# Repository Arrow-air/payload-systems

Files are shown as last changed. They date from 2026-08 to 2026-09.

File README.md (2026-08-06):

# Arrow Payload Systems

Open-source payload systems for Arrow UAV platforms.

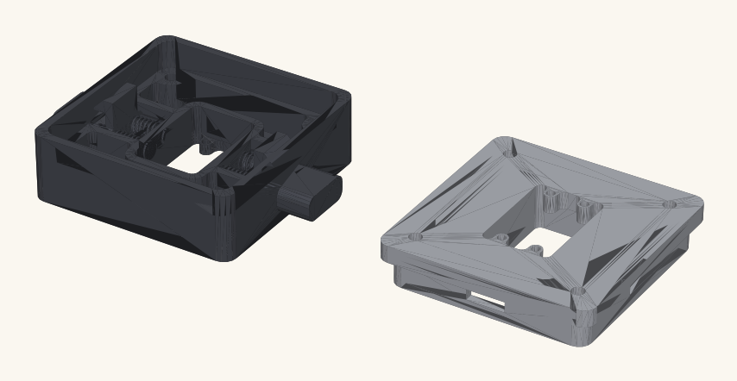
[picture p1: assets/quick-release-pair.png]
The Quiver quick-release pair: aircraft-side plate (left, with spring press-pins and release button) and the payload-side clip plate (right) that every payload bolts to


This repository is the home for community-designed payload attachments that interface with Arrow drones — starting with Quiver, and expanding to cover any Arrow platform that uses the standard attachment interface.

---

## What This Repo Is For

Arrow's drone platforms are designed from the ground up to be modular. The airframe is a carrier; the payload is the mission. This repo exists to:

- Document the **payload attachment interface standard** so anyone can design compatible payloads
- Host **design briefs, specifications, and build documentation** for community payload projects
- Coordinate development across contributors and track progress from concept to flight-ready

If you have an idea for a payload, or want to contribute to one already in progress, this is the place.

---

## The Attachment Interface

The authoritative specification is the **[Interface Control Document (ICD)](interface/ICD.md)** — per-port capabilities, pinouts, power rules, network conventions, and the mechanical mate. Payload designs declare the ICD version they target. Summary:

| Platform | Attachment Interface | Power | Data |
|---|---|---|---|
| **Quiver (PT3+)** | Quick-release, 3× hot-swap points (bottom + 2× side) | 12V_PL all ports (SSR-gated, ~25W guidance); 12VSW bottom only (2A) | Ethernet (all ports), CAN2/DroneCAN (all ports), 1× PWM aux per port |

Key facts (details and caveats in the ICD):

- **The three ports are not identical** — 12VSW and its relay exist only on the bottom port, PWM channel numbers differ per port, and the ports split across two Ethernet switch modules. Check the ICD §2 capability matrix.
- **Blind-mate electrical connection** via the Attachment Interface PCB (V1.4, validated): the aircraft carries spring-loaded pins, the payload side populates landing pads. Design files live in [project-quiver](https://github.com/Arrow-air/project-quiver/tree/main/task-grant-bounty/pt3/electronics/0003-Attachment-Interface-PCB).
- **No 5V, no UART** at the connector — payloads bring their own logic-rail DC-DC.
- **Mechanical mating geometry** (STEP) and mounting-point coordinates are vendored in [`interface/mechanical/`](interface/mechanical/).

---

## Payload Concepts

The following payload types have been identified by the Arrow community as high-value targets. They range from near-term buildable to longer-horizon R&D.

### 🟢 Active / In Progress

| Payload | Status | Thread |
|---|---|---|
| **Multispectral Camera** | Design brief complete, community discussion open | [#multi-spectral-camera](https://discord.com/channels/853833144037277726/1481622578132025364) |

### 🟡 Defined — Ready for Contributors

These payloads have detailed requirements written and are ready for someone to pick up.

| Payload | Description | Requirements Doc |
|---|---|---|
| **Universal Cargo Container** | Fixed or deployable cargo pod; stackable, manually transportable | [project-quiver](https://github.com/Arrow-air/project-quiver/blob/main/task-grant-bounty/equipment/attachment/0002-detailed_attachment_requirement_for_bounty/001-Universal_Cargo_Cont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) |
| **General Aerial LiDAR** | Nadir/forward LiDAR scanner; ≥32 channels, ≥20Hz, ≥1cm accuracy @ 100m | [project-quiver](https://github.com/Arrow-air/project-quiver/blob/main/task-grant-bounty/equipment/attachment/0002-detailed_attachment_requirement_for_bounty/002-General_Aerial_LiDAR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) |
| **Ground Target Machine Vision** | On-board ML inference for target ID/counting; KML/KMZ output | [project-quiver](https://github.com/Arrow-air/project-quiver/blob/main/task-grant-bounty/equipment/attachment/0002-detailed_attachment_requirement_for_bounty/003-Ground_Target_Machin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) |
| **Standard Magnification Camera** | 3-axis gimbaled; ≥1/2" sensor, 24mm + 85mm+ focal lengths | [project-quiver](https://github.com/Arrow-air/project-quiver/blob/main/task-grant-bounty/equipment/attachment/0002-detailed_attachment_requirement_for_bounty/004-Standard_Magnificati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) |
| **General Stabilized Sensor Carrier** | 3-axis gimbal; 1/4-20 mount; 5–8kg capacity; follow-focus optional | [project-quiver](https://github.com/Arrow-air/project-quiver/blob/main/task-grant-bounty/equipment/attachment/0002-detailed_attachment_requirement_for_bounty/005-General_Stabilized_S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) |
| **High Capacity Flood Light** | ~train-light brightness; 45–60° beam; 4000–4500K; flash/breathe modes | [project-quiver](https://github.com/Arrow-air/project-quiver/blob/main/task-grant-bounty/equipment/attachment/0002-detailed_attachment_requirement_for_bounty/006-High_Capacity_Flood_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) |

### 💡 Your idea here

The best payload is the one *you* actually need. Quiver is a multipurpose
platform — if there is an attachment you would use, build it. Sensors,
cargo, lighting, sampling, spraying, comms, safety systems: if it fits the
interface, it can fly. A longer inventory of community-discussed concepts
lives in the [possible attachments document](https://github.com/Arrow-air/project-quiver/blob/main/task-grant-bounty/equipment/attachment/0001-possible_attachment_list/information-note.md)
in project-quiver if you want inspiration.

Start a thread in the Arrow Discord, copy the
[payload template](payloads/_template/), and design against the
[ICD](interface/ICD.md). Payload development can be funded through Arrow
grants & bounties.

---

## How to Contribute

1. **Check the discussions** — see what's already being designed before starting fresh
2. **Open a discussion** — new payload idea? Start a thread and gather input before committing to design
3. **Start from the template** — when a payload is ready for design work, copy [`payloads/_template/`](payloads/_template/) to `payloads/<payload-name>/` and fill in its README (purpose, requirements, target port, ICD version)
4. **Design against the ICD** — any payload targeting Quiver must respect the [ICD](interface/ICD.md): port capabilities, pinout, power rules, and mechanical envelope. Run the ICD §8 checklist before requesting review.

### Repo Layout

```
interface/
├── ICD.md            ← the interface standard (versioned)
├── mechanical/       ← mating STEP files + mounting-point coordinates
└── pcb/              ← pointer to the Attachment Interface PCB in project-quiver
payloads/
├── _template/        ← copy me to start a new payload
└── <payload-name>/   ← one folder per payload: README, cad/, pcb/, software/, docs/
```

Payload folders are created when real design work starts — concepts live in the tables above until then.

---

## Community & Governance

- **Discord:** [#multi-spectral-camera](https://discord.com/channels/853833144037277726/1481622578132025364) and other payload channels in the Arrow server
- **Arrow DAO:** Payload development can be funded via Arrow grants & bounties
- **License:** [CERN-OHL-S v2](LICENSE) — same as project-quiver

---

*This repo is maintained by the Arrow community. All are welcome.*

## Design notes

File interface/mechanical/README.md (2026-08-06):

# Mechanical Interface — Quick-Release Mounting Points

Vendored from project-quiver (BOM 2100, `src/quiver/supporting_structure/attachment_interface/`).
These files are copies for payload-design convenience; the originals in
project-quiver are the source of truth.

## Files

| File | Part | Used |
|---|---|---|
| `2112_attach_plate.step` | Quick-release interface plate (aluminum) — the drone-side mechanism your payload clips into | 3× (all ports) |
| `2112_attach_plate_payload_side.step` | **Payload-side clip plate ("Replaceable Base")** — the part your payload bolts to. 50 × 50 mm footprint, 10.5 mm thick | 1× per payload |
| `2111_attach_spacer.step` | Side-port spacer (PETG) | 2× (left/right) |
| `2131_attach_spacer_bottom.step` | Bottom-port spacer with wiring notch (PETG) | 1× (bottom) |

The plate STEP contains the drone side of the quick-release mechanism
(fixed top, press pins, springs). Your payload provides the mating side.

## The payload-side plate (what your payload bolts to)

The quick-release is a **COTS aluminum clip-plate pair**
([Quick-Release Clip Plate, ~$34](https://www.alibaba.com/product-detail/Quick-Release-Clip-Plate-Clamp-Quick_1600982145247.html),
BOM item 2112 — order **without PCB**). Each set includes both halves:

- **Fixed half** (spring press-pins) — mounted on the aircraft.
- **Clip half** — this is the payload side. Bolt it to your payload's top
  surface, align it with the blind-mate PCB pads (orientation notch on the
  board silkscreen), and it clips into the aircraft's fixed half by hand.

Buy the same product and use the clip half; that guarantees mechanical
compatibility with the flying aircraft. The clip half is modeled in
`2112_attach_plate_payload_side.step` — design your payload's mounting
pattern against it, or start by bolting straight to the physical part.

## Mounting-point positions (drone coordinates)

Frame: origin at airframe center, **+Z up, +Y forward**. Positions are
interface-plate center-of-mass values from the PT3 master model (confirmed
accurate to the flying aircraft, 2026-08).

| Port | Plate position (x, y, z) mm | Mechanism faces |
|---|---|---|
| Bottom | (0, 0, −160.7) | −Z (down) |
| Side 1 / Right | (+185.65, −0.02, −71.0) | +X (outboard) |
| Side 2 / Left | (−185.65, +0.02, −71.0) | −X (outboard) |

The drone-side plate hardware is ~10 mm thick, so a bottom payload's top
mounting plane sits at roughly **Z = −171 mm**. Side ports include a 3 cm
extension adapter for clearance from the airframe body; cable ports face
sideways to prevent abrasion and water ingress.

## Designing the payload side

- Start from the parametric example in project-quiver:
  [`src/quiver/attachments/designs/example_plate/`](https://github.com/Arrow-air/project-quiver/tree/main/src/quiver/attachments/designs/example_plate)
  — it builds a placeholder plate positioned on the bottom interface and can
  render your design in place on the full drone CAD
  (`python -m quiver.attachments.designs.example_plate.assembly --show`).
- Envelope: no formal keep-out volumes are published yet. Practical limits:
  propeller disk clearance for anything wide, ground clearance on landing
  gear for bottom payloads, and the battery-slider travel for side payloads.
  When in doubt, load your STEP against the full drone assembly.

## TODO (tracked)

- [ ] Formal keep-out / envelope STEP exported from the full PT3 assembly
- [ ] Per-port structural mass limits

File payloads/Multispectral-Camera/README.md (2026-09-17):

# Quiver Multispectral Camera Mount V1 (MAPIR Survey3 RGN)

**Status:** flight-tested (prototype, see Remarks for unmet criteria)
**Target port(s):** bottom (as flown), side 1 (design intent)
**ICD version:** 1.0-draft
**Champion:** Erick Perdomo (errrks)
**Discussion:** https://dao.arrowair.com/t/bounty-v1-quiver-multispectral-camera-payload/156

# Status

`Valid, as built at Meetup 2026, flight tested 2026-08-13 (approximate). Information note for project-quiver T-11 (issue #257).`

Built by Erick Perdomo and Alperen with a camera supplied by Thomas. This README is the V1 information note. It records the hardware that flew, the flight controller configuration, the tests run and not run, and what V2 should change. The Meetup 2026 build pack is the design intent and is superseded here where they differ.

# Project Description

Fixed nadir mount for the MAPIR Survey3 RGN multispectral camera. The camera hangs in a printed saddle on four silicone damper balls under the JMRRC quick release clip plate. An LM2596 buck steps 12V_PL down for the camera's USB power input, and the flight controller drives the MAPIR HDMI PWM trigger cable directly over the port's PWM auxiliary channel. No microcontroller, no enclosure, no downlink. Images come off the microSD after flight.

Origin: DAO bounty 156, folded into an in-house meetup build charged to QGB-05. Bounty criteria (fit, stable 5 V power, trigger on each FC pulse, GPS tag, vibration isolation, IP5X dust protection) remain the evaluation baseline.

| | |
|---|---|
| Mass | Not weighed (design estimate ~300 g, built unit lighter) |
| Power | 12V_PL through an LM2596 buck at 5.3 V, ~2 W capturing |
| Data | PWM (FMU_CH1 as flown) |
| Port | bottom as flown, side 1 in design |

# Methodology

1. Parts: MAPIR Survey3 RGN (Thomas's unit), MAPIR HDMI PWM trigger cable, MAPIR USB Power+FPV cable, Zovfam LM2596 buck (Amazon B08BFKKDGD), silicone damper balls from workshop stock, Molex 204523-1201 housing with 79758-1149 leads, JMRRC male clip plate, Attach Interface PCB V1.4 payload side.
2. Printed body, damper plates, and camera saddle in PA6-CF. CAD in `CAD/MAPIR-Survey3N-RGN-adapter.step`.
3. Lens swapped from the wide lens to the narrow lens: unscrew the lens retaining ring, exchange the lens body, refocus by test shots on a distant target.
4. Buck trimmed to 5.3 V at its output, unloaded, before the camera was connected.
5. Flight controller output freed from the GPIO mask, PWM verified on the bench with Mission Planner DO_SET_SERVO at 1000 and 2000 µs.
6. Flight on the bottom port with RC channel 9 triggering. Internal battery removed.

# Results and Deliverables

## Camera

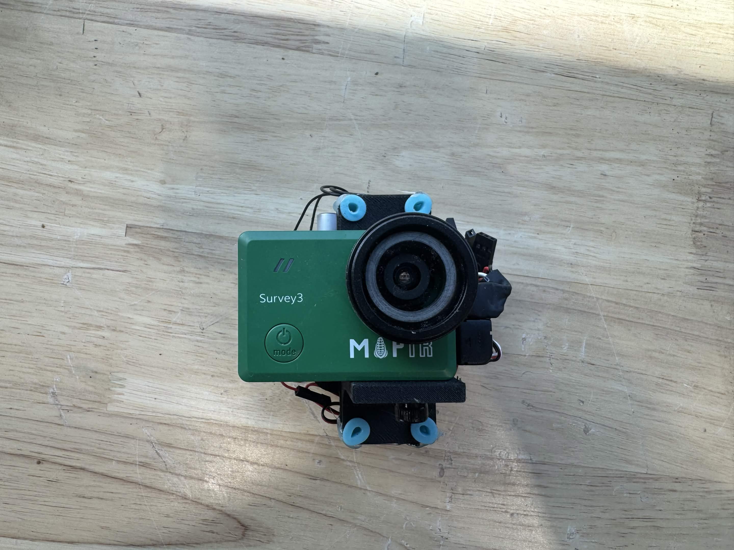
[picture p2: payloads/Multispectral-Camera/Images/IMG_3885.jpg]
Front: Survey3 RGN with the narrow lens, damper balls at the corners


- MAPIR Survey3, classic body, RGN filter, narrow lens (41° HFOV) after the swap.
- Capture mode single photo, RAW on (RAW plus JPG). MAPIR manual v3: RAW is only available in single capture mode.
- Internal battery out. The camera therefore reboots on every 12V_PL cycle.
- Firmware version, SD card model, and cable source not recorded.

## Mount

- JMRRC male clip plate with the Attach Interface PCB V1.4 payload side in its recess.
- PA6-CF body on the plate carries the buck on top and a damper plate below. A second damper plate on the camera saddle. Saddle clamps the camera body with one M3 socket head.
- Four blue silicone damper balls between the plates, hot glued. Source and durometer unknown (workshop stock).
- No enclosure, gasket, or SD door. No outboard arm (not needed on the bottom port). Single load path through the clip plate.
- Zip ties for lead strain relief.

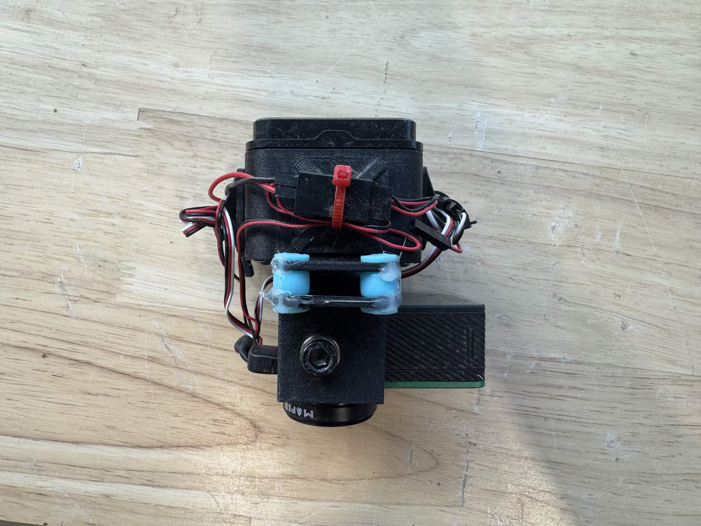
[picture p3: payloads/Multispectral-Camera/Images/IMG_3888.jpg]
Side: damper stack between the plates, saddle clamp bolt, zip tied leads


## Electrical

Power chain: 12V_PL (J1 pin 10) → LM2596 buck IN+ → 5.3 V OUT → MAPIR USB Power+FPV cable spliced to the buck output.

Buck listing specs (2026-09-17): input 3 to 40 V, output 1.3 to 35 V, 2 A continuous, 3 A peak with heatsink, 92% peak efficiency, 65 kHz, 30 mV ripple, thermal shutdown and current limit.

The MAPIR manual v3 states "wall chargers marked output 5V 1A." It does not mention 5.3 V. The 5.3 V setting was measured at the buck output unloaded and worked. The camera end under load was not measured. USB device limit is 5.25 V, so measure the camera end and trim down if needed.

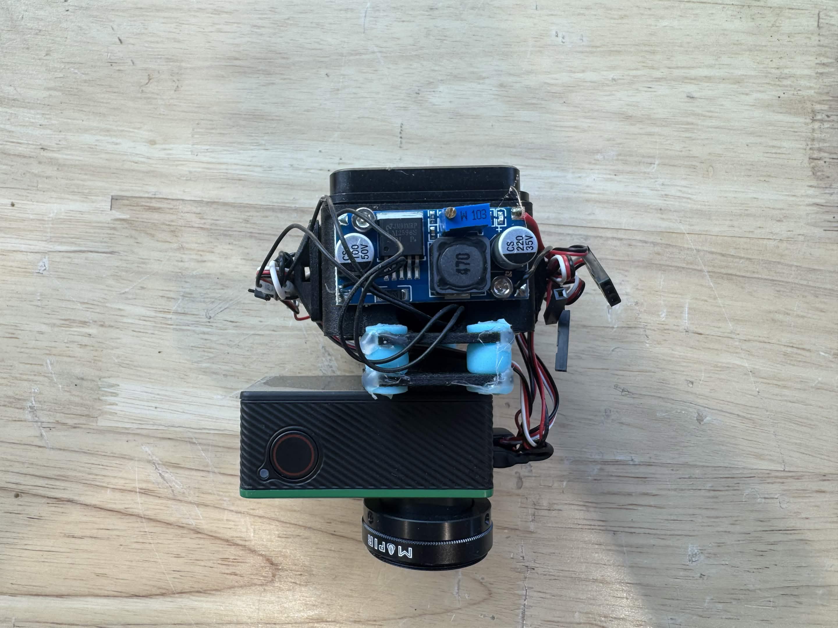
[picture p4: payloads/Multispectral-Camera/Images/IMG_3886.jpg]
Buck on the body top, damper stack, camera below


Harness on Attach Interface PCB J1:

| J1 pin | Signal | Connection |
|---|---|---|
| 8 | GND | Buck IN−, trigger cable ground |
| 10 | +12V (12V_PL) | Buck IN+ |
| 12 | FMU_CH1 | MAPIR trigger cable signal lead |

No inrush limiter, no fuse, no filtering.

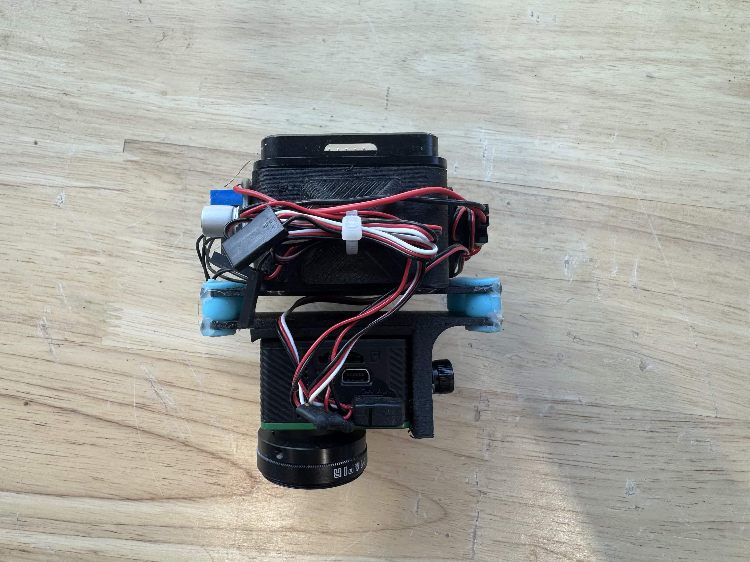
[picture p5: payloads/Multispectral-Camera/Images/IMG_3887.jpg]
Rear: clip plate pogo window, camera HDMI and USB ports with the trigger and power leads


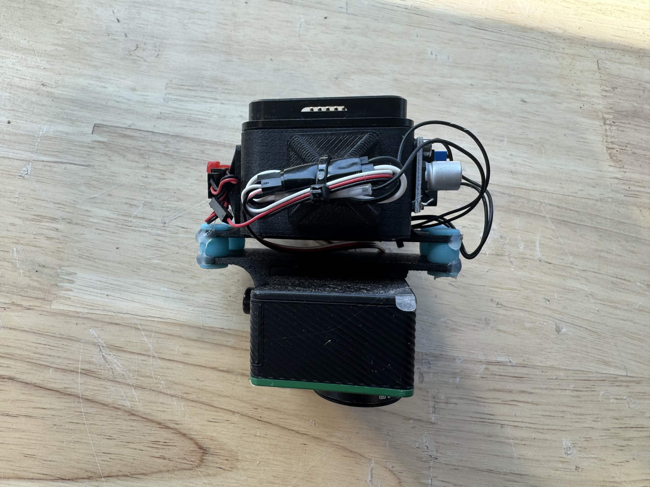
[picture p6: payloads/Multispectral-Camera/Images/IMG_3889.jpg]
Rear, harness dressed: clip plate slot at top, buck trimmer and capacitor at right, damper stack, camera body


## Trigger

FMU_CH1 servo PWM → J1 pin 12 → MAPIR HDMI PWM trigger cable → camera HDMI port. Trigger cable power lead unused.

MAPIR manual v3 PWM levels:

| Pulse | Camera action |
|---|---|
| 1000 µs | Neutral, camera does nothing |
| 2000 µs momentary | Capture |
| 1500 µs momentary | Enter media transfer mode, second pulse exits |

As flown the camera captured on every 2000 µs pulse from the 1000 µs idle.

**1500 µs hazard:** an output resting at trim, a three position switch center, or a slow slider puts the camera into media transfer mode and stops captures until another 1500 µs pulse. Use a two position switch and keep every failsafe path away from 1500.

## Flight controller configuration

Same channel mapping and GPIO mask procedure as the latch README (project-quiver config guide section 11.6). Camera values as flown (from recollection of a rewrite over the latch snapshot, verify on the vehicle):

```
SERVO_GPIO_MASK   12016     ; outputs 9, 15, 16 freed for PWM
SERVO9_FUNCTION   148       ; RCIN9Scaled, RC channel 9
SERVO9_MIN        1000      ; neutral
SERVO9_MAX        2000      ; capture
RELAY6_FUNCTION   1         ; 12V_PL rail (FMU_CH4, pin 53)
RELAY6_PIN        53
RELAY6_DEFAULT    0
```

Bench alternative: `SERVO16_FUNCTION = 0`, MIN/MAX 1000/2000, Servo 16 row High on the Mission Planner Servo/Relay page (side 2 port).

Not used: ArduPilot camera driver (CAM1 is already the SIYI at type 4). Mission triggering by distance is a V2 item and needs a second camera instance.

## Test record

| Test | Result |
|---|---|
| Bench trigger from Mission Planner, output 16 | Captured on every pulse, 2026-08-12 |
| Flight, bottom port, RC channel 9 | Captured on every trigger, RAW plus JPG |
| 12V_PL cycle via Relay 6 | Camera rebooted each cycle, recovered, accepted triggers |
| GPS geotag in EXIF (bounty GPS Tag) | Not checked. Camera top face points into the belly, no sky view |
| Camera end voltage under load (bounty Power) | Not measured |
| Mass (350 g budget) | Not weighed |
| IP5X (bounty Dust Protection) | Not built |

Photos in `Images/` (IMG_3885 to IMG_3889). Video: Arrow Discord and Twitter, meetup week of 2026-08-10.

## Deliverables

- `CAD/MAPIR-Survey3N-RGN-adapter.step`, `.stl` (CERN OHL-S v2)
- This README (CC BY 4.0)
- Flight controller configuration section 11.6 in project-quiver

# Remarks

1. **Geotag unverified and probably absent.** On the bottom port the built in GPS antenna faces the 2 mm aluminum lower plate. Pull the SD and check EXIF. V2 restores sky view on a side port or feeds NMEA from the vehicle.
2. **Power criterion open.** 5.3 V set unloaded at the buck, not locked, camera end not measured. The manual's stated requirement is 5 V 1 A.
3. **1500 µs media transfer mode.** Any output parked at trim stops captures. Guard in the RC setup and in any future camera driver integration.
4. **Battery out means a reboot on every rail cycle.** Camera boot time before it accepts triggers is unrecorded. Measure and add to the ground procedure. Battery in (the original decision) survives rail cycles but needs the charge current and thermal check.
5. **Capture interval.** RAW plus JPG limits capture to roughly one per 2.5 to 3 s. Faster mission triggering drops frames silently.
6. **No enclosure, no inrush, no fuse.** IP5X criterion not attempted.
7. **Dampers.** Unknown durometer, hot glued. Vibration isolation criterion asks for a documented spec.
8. **Bottom port sharing with the latch.** SERVO9 endpoints differ (1000/2000 vs 1315/1750) and both use RC channel 9. Rewrite at every swap.
9. **Lens swap.** Filter position during the swap not recorded. Confirm with Thomas whether the RGN filter is lens mounted or sensor mounted on this unit.
10. **Print material.** All printed parts are PA6-CF (confirmed 2026-09-17), not the PETG-CF called out in the meetup build conventions. Dry the filament before printing. Heat set insert bores may creep if parts are stored humid. Filament brand and drying procedure not recorded.

# V2 Recommendations

- Side port mount with a plain PETG GPS window per the build pack, or vehicle NMEA to the camera.
- Gasketed enclosure with SD door for IP5X.
- Second ArduPilot camera instance (servo type) for mission triggering, with 1500 µs excluded from every path.
- Buck enclosure, trimmer lock, inrush NTC, local fuse.
- Measured mass, camera end voltage under load, boot time after rail power.
- Decide battery in or out. Record the damper spec.

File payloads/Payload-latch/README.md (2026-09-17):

# Quiver Actuated Payload Latch V1

**Status:** flight-tested (prototype, see Remarks for unmet criteria)
**Target port(s):** bottom
**ICD version:** 1.0-draft
**Champion:** Erick Perdomo (errrks)
**Discussion:** https://dao.arrowair.com/t/bounty-v1-quiver-actuated-payload-latch/155

# Status

`Valid, as built at Meetup 2026, flight tested 2026-08-13 (approximate). Information note for project-quiver T-11 (issue #257).`

Built by Erick Perdomo and Alperen. This README is the V1 information note. It records the hardware that flew, the flight controller configuration that drove it, the tests that were and were not run, and what V2 should change. The design intent lives in the Meetup 2026 build pack and is superseded here where they differ.

# Project Description

Servo actuated cargo hook for slung loads on the Quiver bottom port. An off the shelf aluminum sliding pin release block, driven by a standard size servo, is carried on a printed PA6-CF bracket bolted to the JMRRC quick release clip plate. The flight controller drives the servo directly over the port's PWM auxiliary channel. There is no microcontroller and no return spring in V1.

Origin: DAO bounty 155 ($500 USDC, unclaimed), folded into an in-house meetup build charged to QGB-05. The bounty requirements (2 kg safe working load, under 250 g, 3.3 V GPIO trigger, mechanically closed on power loss, 20 cycle reliability) remain the evaluation baseline. See Remarks for which are met.

| | |
|---|---|
| Mass | Not weighed (design estimate ~240 g) |
| Power | 12V_PL through an LM2596 buck at 6 V. Idle under 1 W, servo stall bound ~15 W for under 1 s |
| Data | PWM (FMU_CH1) |
| Port | bottom |

# Methodology

1. Parts per the meetup build pack BOM: powerday 995 alloy release unit (Amazon B07HKF6C5P), Deegoo-FPV MG995 servo (Amazon B07NQJ1VZ2), Zovfam LM2596 buck 10 pack (Amazon B08BFKKDGD), Molex 204523-1201 housing with 79758-1149 pre-crimped leads, JMRRC male clip plate, Attach Interface PCB V1.4 payload side.
2. Bracket modeled and printed in PA6-CF, heat set M3 inserts for the servo frame. CAD in `CAD/V1-Servo-Payload-Mount.step`.
3. Servo endpoints measured at linkage fitting with the servo on a bench PWM source: 1315 µs pin home, 1750 µs pin retracted.
4. Buck trimmed to 6 V at its output with a DMM, unloaded, before the servo was connected.
5. Flight controller outputs freed from the GPIO mask and configured for RC passthrough (see Results, FC configuration).
6. Bench cycles from Mission Planner on outputs 9, 15, and 16, then two flights with a 370 g load and one 1 kg drop.

# Results and Deliverables

## Mechanism

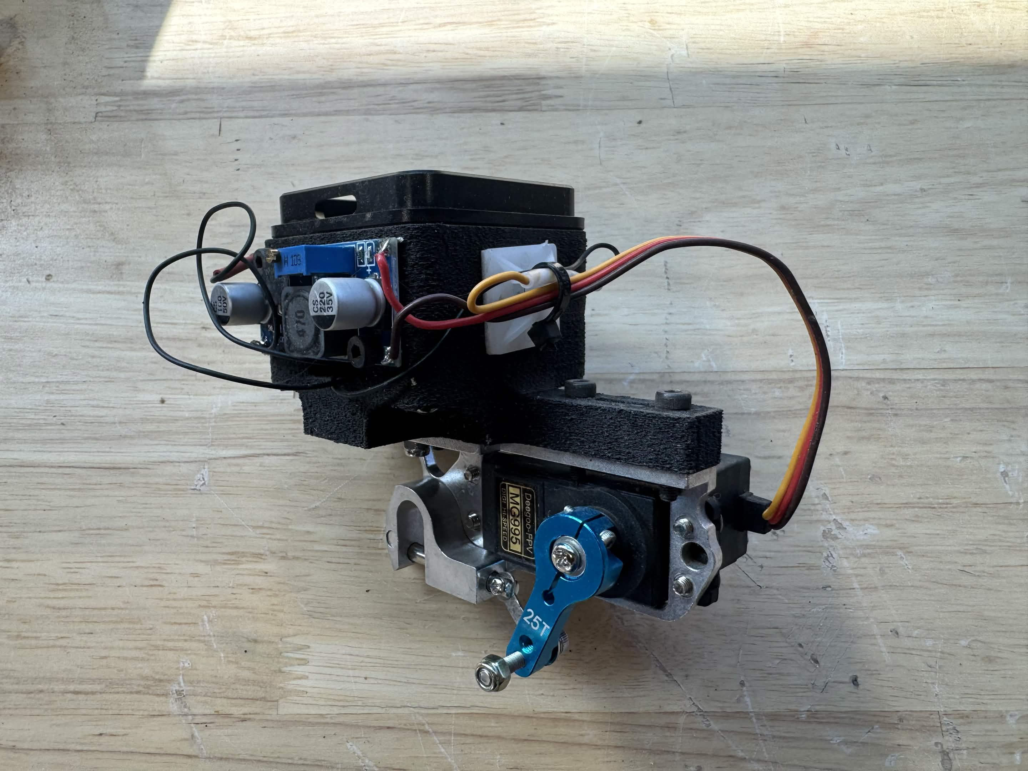
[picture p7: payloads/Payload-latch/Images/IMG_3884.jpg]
Assembly overview: buck on the bracket top, powerday block and MG995 below


- powerday 995 aluminum pin block with its servo frame. MG995 with a blue 25T aluminum horn. M3 bolt and nyloc nut as the linkage pivot.
- **No return spring.** The servo drives and holds the pin in both positions. With power removed the pin is retained by gear friction only.
- One L shaped PA6-CF bracket. Four M3 socket heads into heat set inserts hold the servo frame. The buck sits exposed on the bracket top face. The bracket bolts to the JMRRC male clip plate, which carries the Attach Interface PCB V1.4 payload side (10 pads) on 4× M2.
- Printed zip tie saddle on the bracket side for lead strain relief.
- Single structural path through the clip plate. No secondary strap.

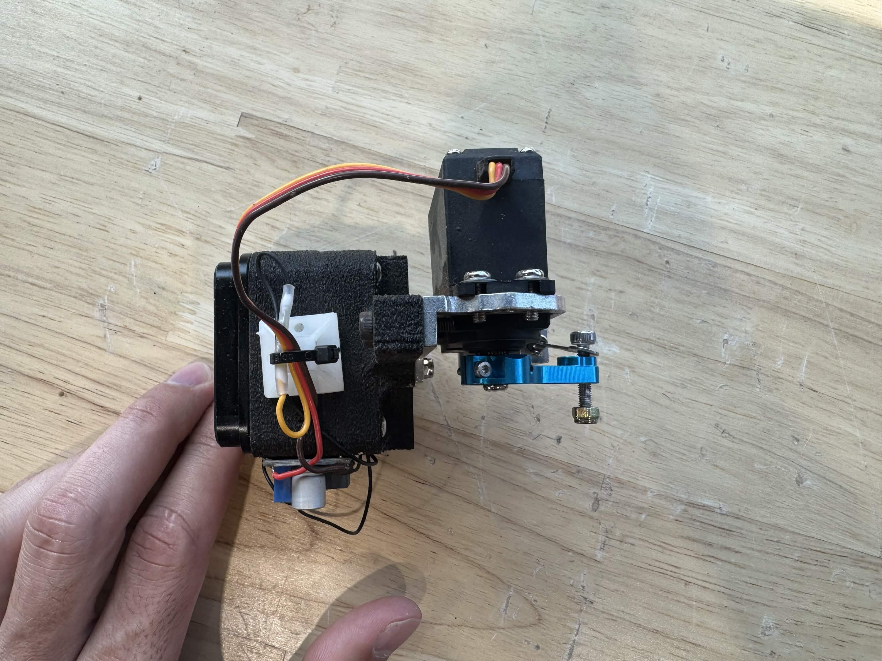
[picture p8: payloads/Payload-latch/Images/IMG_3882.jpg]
Side view: servo on the aluminum frame, 25T horn, linkage to the pin carrier, zip tie saddle


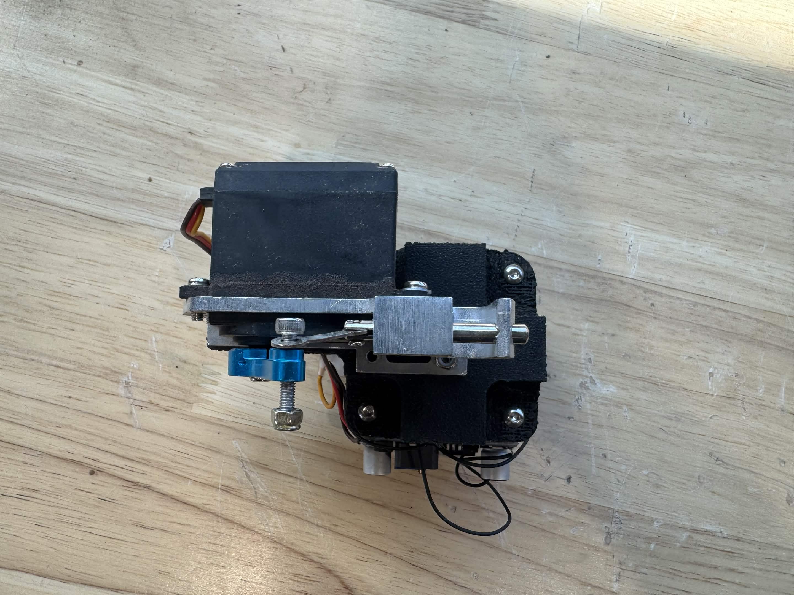
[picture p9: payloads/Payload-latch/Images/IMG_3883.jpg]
Underside: pin extended through the block, linkage pivot bolt


## Electrical

Power chain: 12V_PL (J1 pin 10) → LM2596 buck IN+ → 6 V OUT → servo. Servo power leads soldered to the buck output pads.

Buck listing specs (2026-09-17): input 3 to 40 V, output 1.3 to 35 V, 2 A continuous, 3 A peak with heatsink recommended above 2 A or 15 W, 92% peak efficiency, 65 kHz, thermal shutdown and current limit, 43 × 21 × 14 mm.

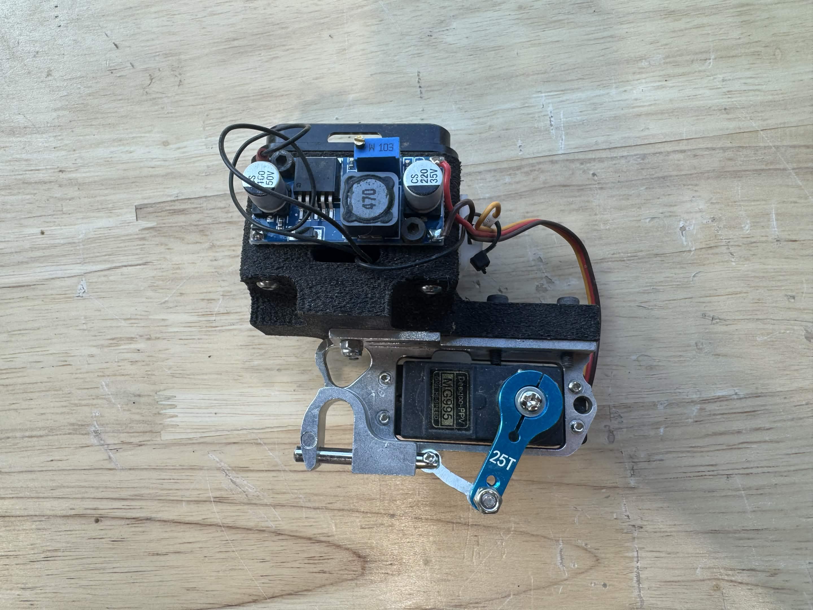
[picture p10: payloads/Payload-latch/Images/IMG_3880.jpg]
Top view: LM2596 buck with trimmer and capacitors exposed, Molex housing to the right


Harness on Attach Interface PCB J1:

| J1 pin | Signal | Connection |
|---|---|---|
| 8 | GND | Buck IN−, servo ground via buck OUT− |
| 10 | +12V (12V_PL) | Buck IN+ |
| 12 | FMU_CH1 | Servo signal lead, solder heat shrink joint |

No inrush limiter, no fuse, no series resistor, no pulldown, no bulk capacitor beyond the buck's own output cap.

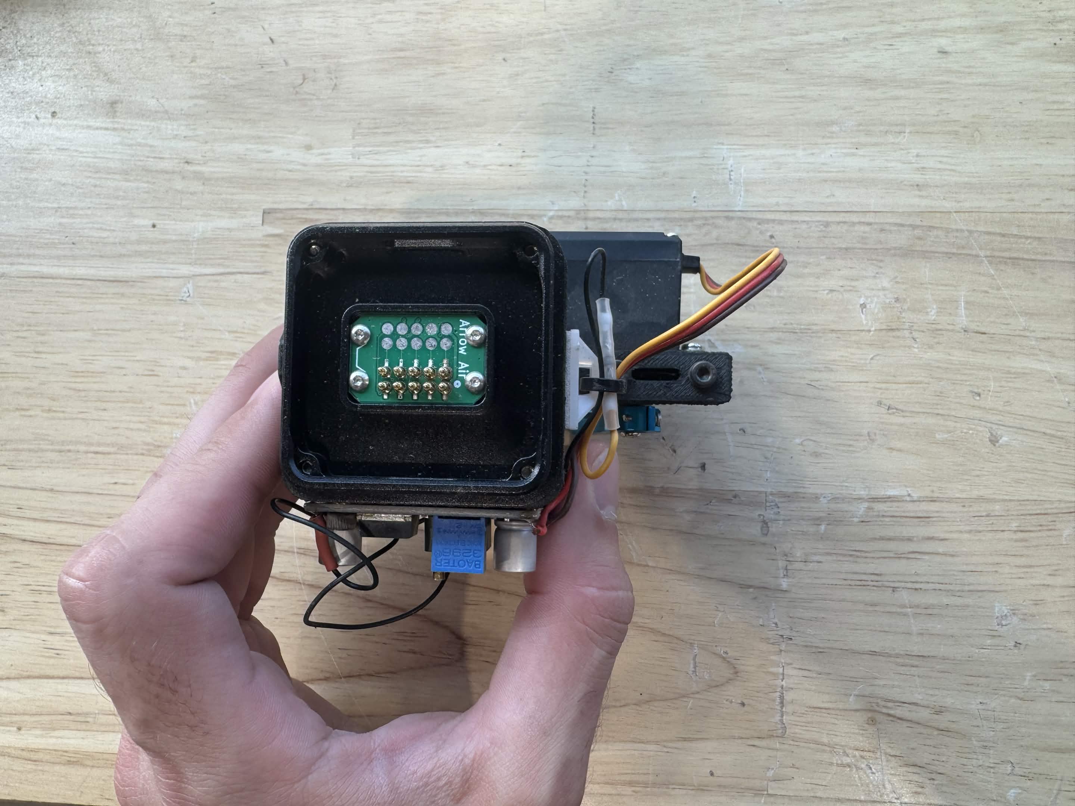
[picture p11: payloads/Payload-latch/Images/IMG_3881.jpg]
Clip plate face: Attach Interface PCB V1.4 payload side in the recess, zip tie saddle and signal joint at right


## Flight controller configuration

Confirmed on the second Dev-Kit, 2026-08-12. Full procedure in project-quiver `docs/Operations/Initial-Configuration-Guide.md` section 11.6.

| Port | FC pin | ArduPilot output |
|---|---|---|
| Bottom | FMU_CH1 | SERVO9 |
| Side 1 | FMU_CH7 | SERVO15 |
| Side 2 | FMU_CH8 | SERVO16 |

The HOU baseline ships `SERVO_GPIO_MASK = 65520`, claiming outputs 5 through 16 as GPIO. A masked output produces no PWM. Clear the bit for the port in use (bottom only: 65264, all three payload channels: 16112), write, reboot. The flown unit used 12016.

Latch parameters as flown (from a work in progress snapshot, verify on the vehicle):

```
SERVO_GPIO_MASK   12016     ; outputs 9, 13, 15, 16 freed for PWM
SERVO9_FUNCTION   148       ; RCIN9Scaled, RC channel 9 scaled into MIN/MAX
SERVO9_MIN        1315      ; locked
SERVO9_MAX        1750      ; released
RELAY6_FUNCTION   1         ; 12V_PL rail (FMU_CH4, pin 53)
RELAY6_PIN        53
RELAY6_DEFAULT    0
```

Bench alternative: `SERVO9_FUNCTION = 0` and drive the Servo 9 row on the Mission Planner Flight Data → Servo/Relay page with Low/High typed as 1315/1750.

Transmitter: any radio with channel 9 on a two position switch. Low is locked. The switch is the operator's choice.

Ground procedure: Relay 6 on, confirm the pin is home, load the ring or loop onto the pin, arm. Any Relay 6 toggle in flight power cycles the latch.

## Test record

| Test | Result |
|---|---|
| Bench, no load, repeated cycles from outputs 9, 15, 16 | Passed |
| Two flights, 370 g bottle on a zip tie loop, drops at 10 m and 5 m, RC channel 9 | Released cleanly both times, mechanism unaffected |
| 1 kg first aid kit drop | Released cleanly |
| 2 kg static load, 20 cycles (bounty reliability) | Not run |
| Power loss with load hanging (bounty failsafe) | Not run |
| RC failsafe behavior | Not run |
| Mass, current, buck under load | Not measured |

Photos in `Images/` (IMG_3880 to IMG_3884). Drop videos: Arrow Discord and the Arrow Twitter account, meetup week of 2026-08-10.

## Deliverables

- `CAD/V1-Servo-Payload-Mount.step`, `.stl` (CERN OHL-S v2)
- This README (CC BY 4.0)
- Flight controller configuration section 11.6 in project-quiver

# Remarks

1. **Failsafe criterion not met.** No spring. An unpowered servo holds the pin by friction only, and 12V_PL drops on every Relay 6 cycle and reboot. Untested with load. V2 needs a mechanical lock on power loss.
2. **Reliability criterion not run.** 20 cycles at 2 kg still owed. Flown loads were 370 g and 1 kg.
3. **Structure.** Single load path through the clip plate. The ICD and the requirement docs ask for two rigid connections or a rated tether.
4. **Electrical protection.** No inrush limiting (AB-1), no local fuse, exposed buck and trimmer, trim set unloaded and not locked. A stalled MG995 (~2.5 A at 6 V) exceeds the buck's 2 A continuous rating and relies on the module's thermal shutdown.
5. **Signal loss.** No pulldown. Servo behavior with a floating signal is the retention path when the FC output stops. Characterize it.
6. **Bottom port sharing.** The V1 multispectral camera also flies on the bottom port with SERVO9 at 1000/2000. Swapping payloads means rewriting SERVO9_MIN/MAX. A stale 1000 µs low endpoint drives the latch servo past its lock stop.
7. **Parameter snapshot.** The saved WT file is work in progress and also carries `SERVO13_FUNCTION = 148`, presumed a leftover. Verify against the live vehicle.
8. **Print material.** All printed parts are PA6-CF (confirmed 2026-09-17), not the PETG-CF called out in the meetup build conventions. Dry the filament before printing. Heat set insert bores may creep if parts are stored humid. Filament brand and drying procedure not recorded.

# V2 Recommendations

- Mechanical lock on power loss: return spring or over center pin geometry.
- Enclosed electronics: buck in a printed pocket, trimmer locked, leads captive.
- Inrush NTC and local fuse on the 12 V input.
- Second structural path.
- Larger packages with a different loading and unloading mechanism (Erick).
- Measured mass, servo hold and stall current at 6 V, buck temperature.
- Keep FC only PWM or reintroduce an MCU for debounce, stall guard, and signal loss lock. Decide from the signal loss test.
- Per payload parameter file for bottom port hot swaps, or dedicate ports.

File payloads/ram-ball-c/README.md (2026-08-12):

# RAM Ball C

**Status:** prototype (first article printed in PA6-CF)
**Target port(s):** bottom / side 1 / side 2 (mechanical-only payloads work on any port)
**ICD version:** 1.0

One 3D-printed part that bolts to the payload-side quick-release clip plate
and exposes a **1.5" RAM Size-C ball**, so anything in the RAM ecosystem
(double-socket arms, cradles, cameras, antennas…) can hang off a Quiver
mounting point and be re-aimed without tools. Wiring from the attachment interface PCB
still comes through.

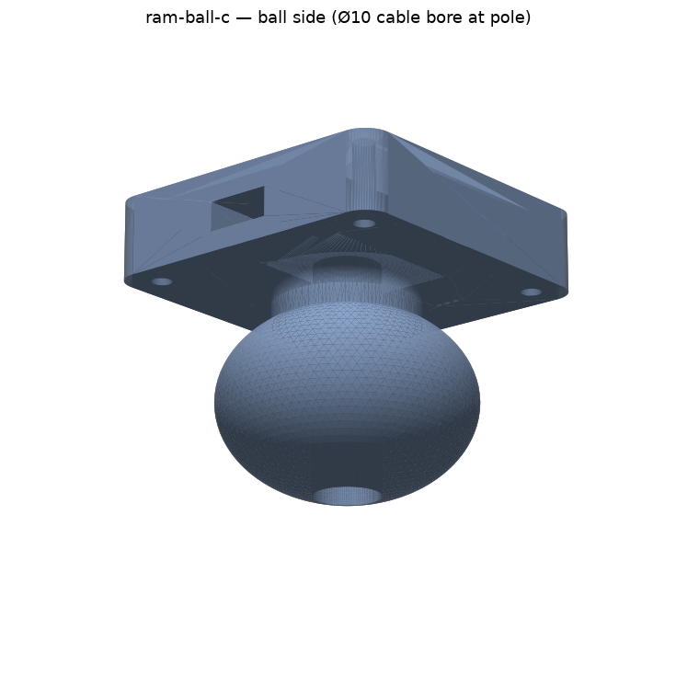
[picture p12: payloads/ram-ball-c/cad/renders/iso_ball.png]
ball side


## What it does

Clips onto any Quiver port via the standard quick-release, presents a Size-C
ball pointing away from the aircraft (down on the bottom port, outboard on the
sides). Two wiring routes from the attachment interface PCB:

- **Side channel** — 10 × 6 mm slot from the PCB well out the −Y face.
- **Axial bore** — Ø10 mm straight down the neck and out the ball's bottom
  pole, for wiring that should arrive at the mounted device. The bore exits
  inside the pole cap (~15° half-angle), well clear of the band a RAM socket
  clamps (verified: surface solid ±45° around the equator).

## Requirements

| | |
|---|---|
| Mass | ~75 g printed solid + clip half + fasteners ≈ 150 g, before the RAM arm and device |
| Power | none itself; pass-through wiring only |
| Data | pass-through wiring only |
| Port | any |

Load guidance: RAM rates C-size arms to roughly 1–2 kg in vibration
environments. Keep the hung mass + arm well inside the platform's payload
budget and treat >1 kg on a printed ball as needing a pull test first (same logic as the
capsule dispenser's RT-13 retention test).

## Geometry provenance

Interface dims are **measured, not assumed** — they come from the
capsule-dispenser r6 containment scan of
[`2112_attach_plate_payload_side.step`](../../interface/mechanical/)
(see `capsule-dispenser/cad/dispenser.py`, "clip-plate map"; r5 of that
project bolted into the blind-mate window by trusting eyeballed numbers):

- mount pattern 4× Ø3 at (±19, ±19)
- blind-mate shaft 16 × 24 through the plate; the payload-side pads PCB
  mounts to the plate's own tabs and hangs below it
- clip plate 50 × 50 × 10.5 mm

The part's well (16.6 × 24.6 × 12 deep, sharp corners) swallows the PCB, its
Molex J1 and a service loop. The square mount pattern *could* be assembled
90° off — but then the plate's 16 × 24 shaft crosses the well and the PCB
lands on the well rim, so wrong assembly is physically blocked. Engraved
triangle on the +Y wall (apex toward the plate) marks aircraft-forward on
the bottom port.

## Build

- **Print:** PA6-CF is what the first article was printed in and is ideal
  (stiff, strong, wear-resistant ball surface); PETG/ASA also work. 100 %
  infill (it's small; the ball and neck carry the load), 0.12–0.16 mm
  layers, ball-side up with the top face on the bed.
  The well roof and slot bridge ≤ 16 mm — no supports needed; supports OFF
  under the ball (the tangent neck keeps overhangs gradual).
- **Hardware:** 4× Ø3.2 mounting holes straight through the 16 mm body,
  matching the clip half's (±19, ±19) pattern (BOM 2112, see
  [`interface/mechanical/`](../../interface/mechanical/README.md)).
- A rigid printed ball grips fine in RAM arms but damps less than RAM's
  rubberized balls; if a device turns out vibration-sensitive, the fix is at
  the device end (RAM shock plate) or a marine-grade steel C ball on a
  50 × 50 AMPS adapter plate instead of this part.

## Folder layout

- `cad/ram_ball_c.py` — parametric source (build123d). Running it exports
  `ram_ball_c_adapter.stl` / `.step` next to itself.
- `cad/verify_ram_ball_c.py` — independent checks on the exports (trimesh
  containment + STEP face queries): envelope, mount-hole pattern, well clear of
  the full board footprint, both cable paths, ball diameter, clamp-band
  integrity. All 12 pass on the committed exports.
- `cad/renders/` — preview renders.

## Compliance

ICD §8: mechanical-only payload; no power drawn, no CAN termination, no
network presence. Envelope: 48 × 48 mm footprint inside the 50 × 50 clip
plate, 58.6 mm tall below the mating plane — on the bottom port the ball
bottom sits at Z ≈ −230, far above landing-gear ground contact (≈ −548).
Nothing protrudes above the mating plane.

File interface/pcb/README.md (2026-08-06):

# Attachment Interface PCB — pointer

The blind-mate PCB design lives in project-quiver and is **not duplicated
here**:

- Current revision: **V1.4** —
  [`0003-Attachment-Interface-PCB/2026-Update/`](https://github.com/Arrow-air/project-quiver/tree/main/task-grant-bounty/pt3/electronics/0003-Attachment-Interface-PCB/2026-Update)
  (spring-loaded pin blind-mate, validated)
- Original v1.2 documentation and pinout:
  [`0003-Attachment-Interface-PCB/README.md`](https://github.com/Arrow-air/project-quiver/blob/main/task-grant-bounty/pt3/electronics/0003-Attachment-Interface-PCB/README.md)

**For payload designers:** you populate the **pads-only side** (U11–U20
landing pads); the aircraft carries the spring pins. Order the same board,
populate per your side, mount with 4× M2. Electrical details and the
CAN1→CAN2 labelling caveat are in the [ICD](../ICD.md) §5.

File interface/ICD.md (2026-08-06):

# Quiver Payload Attachment Interface — Interface Control Document (ICD)

**ICD version:** 1.0-draft
**Applies to:** Quiver PT3 and later
**Source of truth:** the aircraft-side hardware is owned by
[project-quiver](https://github.com/Arrow-air/project-quiver). This document is
derived from the canonical KiCad sources (`src/pcb/main_pcb/`) and CAD
(`src/quiver/supporting_structure/attachment_interface/`) and is versioned so
payload designs can declare what they were built against. If this document and
the project-quiver sources disagree, the sources win — and please file an issue.

---

## 1. Overview

Quiver carries payloads on **three hot-swappable quick-release mounting
points**: one on the belly (bottom) and one on each side of the battery
compartment. Each point provides the same mechanical mate and a blind-mate
electrical connection carrying power, Ethernet, CAN, and one PWM auxiliary
channel. Payloads require no tools to install or remove.

Platform budget: **25 kg MTOW, 5–8 kg total payload capacity** across all
mounting points. Per-port structural limits are not yet formally specified;
see §6.

## 2. Port capability matrix

The three ports are **not identical**. Design against the port you target:

| Capability | Bottom (J31) | Side 1 / Right (J29) | Side 2 / Left (J30) |
|---|---|---|---|
| **12V_PL** — main 12 V payload rail | ✓ | ✓ | ✓ |
| **12VSW** — relay-switched 12 V (2 A fused) | ✓ | — | — |
| **CAN2** (DroneCAN) | ✓ | ✓ | ✓ |
| **Ethernet** 100BASE-T | ✓ (switch 1) | ✓ (switch 1) | ✓ (switch 2) |
| **PWM aux channel** | FMU_CH1 | FMU_CH7 | FMU_CH8 |
| Suggested static IP | 192.168.144.100 | 192.168.144.101 | 192.168.144.102 |

## 3. Power

### 12V_PL (all ports)
- Sourced from the Main PCB 12 V rail through two series fuses and a
  **solid-state relay (U5)** controlled by flight-controller channel
  **FMU_CH4**. Enabled by default in the standard configuration, so it behaves
  as always-on — but it is *not* hardwired. The FC can drop and restore the
  rail (e.g. to hard power-cycle a hung payload). **Payloads must tolerate
  power appearing late, being removed at any time, and repeated cycling.**
- The rail is shared by all three ports: one SSR, common fusing. Budget
  guidance: design within **~25 W per port** and verify total draw against
  Main PCB limits before exceeding.

### 12VSW (bottom port only)
- 12 V switched through mechanical relay **K1** (SPST-NO, controlled by
  **FMU_CH2**), fused at **2 A** (F1). Intended for FC-commanded on/off loads
  (originally the brush-bullet dispenser motor). Max ~24 W.

### Other voltages
- **No 5 V or 3.3 V is provided.** Payloads needing logic rails bring their own
  DC-DC (e.g. Mean Well SD-25B-05 class buck for 5 V).
- **No UART** is available at the payload connector.

## 4. Data

### Ethernet
- 100BASE-T, one TX and one RX differential pair per port, via two Ethernet
  switch modules on the Main PCB (bottom and side 1 on switch 1, side 2 on
  switch 2).
- The Quiver network is a **flat static 192.168.144.0/24 — no DHCP** (Siyi
  firmware conflicts with DHCP servers). Payloads use static IPs from the
  developer range **.100–.199**; recommended per-port assignments in §2.
- Reserved addresses (do not use): .11, .12, .20, .25, .50 (companion Pi),
  .51 (flight controller), .60. See the
  [Quiver SDK Developer Guide](https://github.com/Arrow-air/project-quiver/blob/main/docs/Develop-Attachments-Software/Quiver-SDK-Developer-Guide.md)
  for the full map and the companion-computer service architecture.

### CAN
- **CAN2 bus, DroneCAN protocol**, shared by all three ports plus the
  companion computer. A 120 Ω termination (R14) is switchable on the Main PCB
  (S2). **Payloads must not add bus termination** without coordinating with
  the airframe configuration.

### PWM auxiliary
- One direct flight-controller PWM output per port (see §2 for channel
  mapping). Note the channel differs per port — firmware/Lua that assumes
  FMU_CH1 only works on the bottom port.

## 5. Connector chain and pinouts

Main PCB (J31/J29/J30 power+CAN+PWM, 6-pos 2.50 mm; J39/J37/J38 Ethernet,
4-pos) → harness → **12-pin Molex locking connector** on the Attachment
Interface PCB → **spring-pin blind-mate** across the quick-release → payload.

### Attachment Interface PCB (the blind-mate)
- Design files: [project-quiver `0003-Attachment-Interface-PCB`](https://github.com/Arrow-air/project-quiver/tree/main/task-grant-bounty/pt3/electronics/0003-Attachment-Interface-PCB),
  current revision **V1.4** (`2026-Update/`).
- One board layout serves both sides: the **drone side populates spring-loaded
  pins (U1–U10)**; the **payload side populates only the enlarged landing pads
  (U11–U20)**. Alignment is provided by the quick-release mechanism; a
  silkscreen notch marks orientation.
- The spring-pin mate configuration is **validated** (electrically tested).
- Board: 23.5 × 15.8 mm, 1.2 mm FR4, 4× M2 mounting holes.

**10-pin blind-mate pinout** (drone-side pins → payload-side pads):

| Pin | Function |
|---|---|
| 1 | ETH_RX+ |
| 2 | 12VSW *(bottom port only; unconnected on sides)* |
| 3 | ETH_RX− |
| 4 | GND |
| 5 | ETH_TX+ |
| 6 | +12V (12V_PL) |
| 7 | ETH_TX− |
| 8 | FMU_CHx (per-port channel, §2) |
| 9 | CAN2_H *(labelled CAN1_P on board)* |
| 10 | CAN2_L *(labelled CAN1_N on board)* |

**12-pin Molex J1** (harness side, Molex 2077601281 / mate 2045231201):
doubled power and ground pins for current capacity — pinout in the
[Attachment Interface PCB README](https://github.com/Arrow-air/project-quiver/blob/main/task-grant-bounty/pt3/electronics/0003-Attachment-Interface-PCB/README.md).

## 6. Mechanical

See [`mechanical/`](mechanical/) for the vendored STEP files, mounting-point
positions in drone coordinates, and envelope guidance. Summary:

- The quick-release mechanism is a **COTS aluminum clip-plate pair** (BOM
  2112): the aircraft carries the fixed half (spring press-pins) at each
  port; **your payload carries the mating clip half of the same product** —
  see `mechanical/` for ordering info. PETG spacers mount the aircraft-side
  plates to the airframe. Side ports sit on 3 cm extension adapters for body
  clearance; the bottom spacer has a wiring notch.
- Drone coordinate frame: **origin at airframe center, +Z up, +Y forward.**
  Bottom interface plate at Z ≈ −160.7 (payload mounting plane ≈ −171);
  side plates at X ≈ ±185.7.
- Per-port structural mass limits: **not yet formally specified** — the
  platform-level 5–8 kg budget governs. Heavy payloads (>3 kg on a single
  port) should be reviewed against the airframe before flight.

## 7. Software integration

Payloads integrate through the companion computer (Raspberry Pi, .50):
DroneCAN devices are bridged to telemetry; Ethernet payloads get REST/WebSocket
pipelines to Quiver Hub (telemetry, point cloud, camera/WebRTC, custom payload
apps). Start with the
[Quiver SDK Developer Guide](https://github.com/Arrow-air/project-quiver/blob/main/docs/Develop-Attachments-Software/Quiver-SDK-Developer-Guide.md).

## 8. Designing a payload — checklist

1. Pick your port(s) from the capability matrix (§2).
2. Mechanical: mate to the quick-release plate; stay inside the envelope
   (§6 / `mechanical/`); mind prop clearance for wide payloads.
3. Electrical: payload-side Attachment Interface PCB (pads-only population),
   own DC-DC for logic rails, tolerate 12V_PL power cycling, no CAN
   termination.
4. Network: static IP in the assigned range, or DroneCAN on CAN2.
5. Software: integrate via the SDK guide's payload pipelines.
6. Declare the ICD version your design targets in your payload README.

## Revision history

| ICD version | Date | Changes |
|---|---|---|
| 1.0-draft | 2026-08-06 | Initial ICD from verified PT3 Main PCB (current KiCad netlist), Attachment Interface PCB V1.4, and BOM 2100 CAD. |

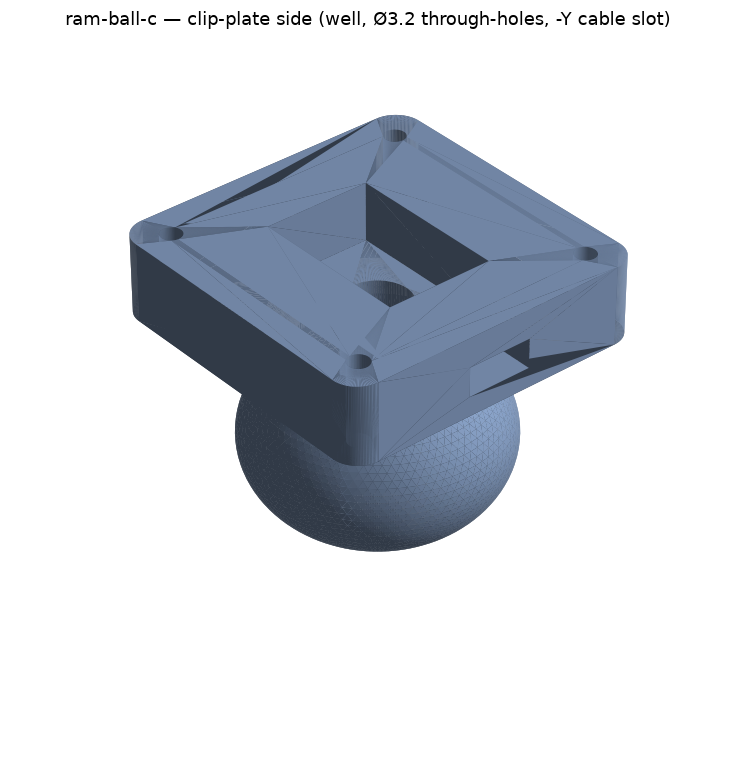
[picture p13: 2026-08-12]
payloads/ram-ball-c/cad/renders/iso_top.png

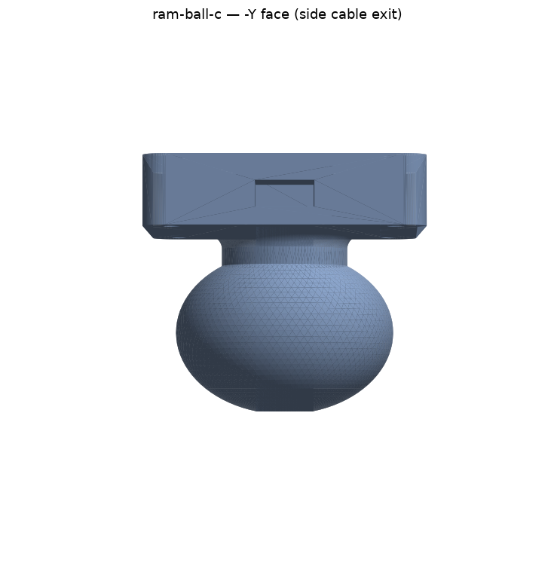
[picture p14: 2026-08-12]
payloads/ram-ball-c/cad/renders/front.png

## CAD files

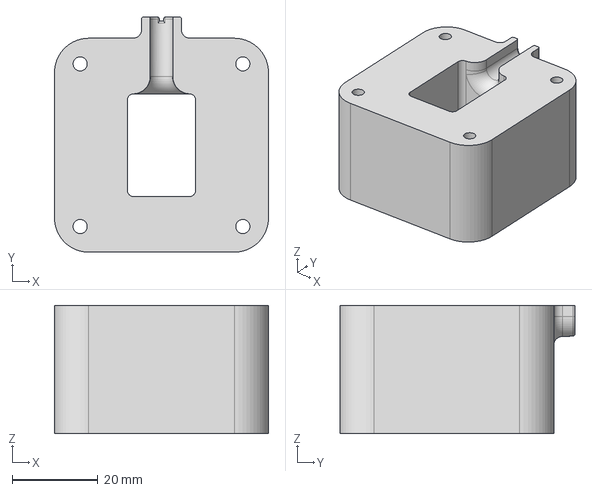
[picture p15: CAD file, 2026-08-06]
interface/mechanical/2131_attach_spacer_bottom.step
50.0 x 55.0 x 30.0 mm

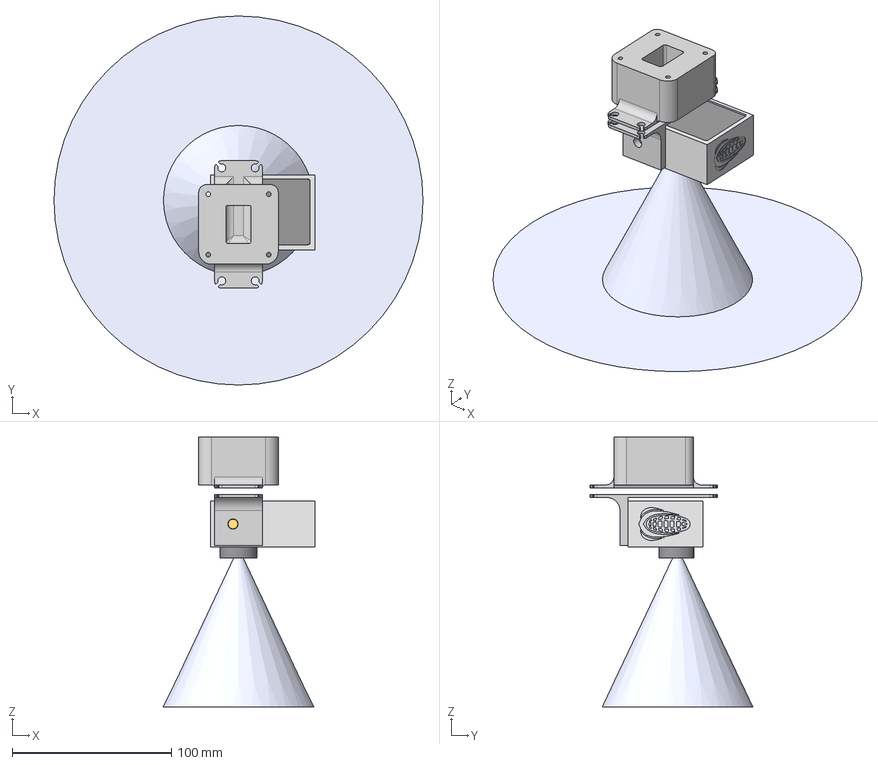
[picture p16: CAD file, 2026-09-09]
payloads/Multispectral-Camera/CAD/MAPIR-Survey3N-RGN-adapter.step
231.8 x 231.8 x 169.5 mm
Survey3W_Camera
3.37mm_lens_FOV
Survey3N_Camera
8.25mm_lens_FOV
Survey3_Holder_Example
adapter_1

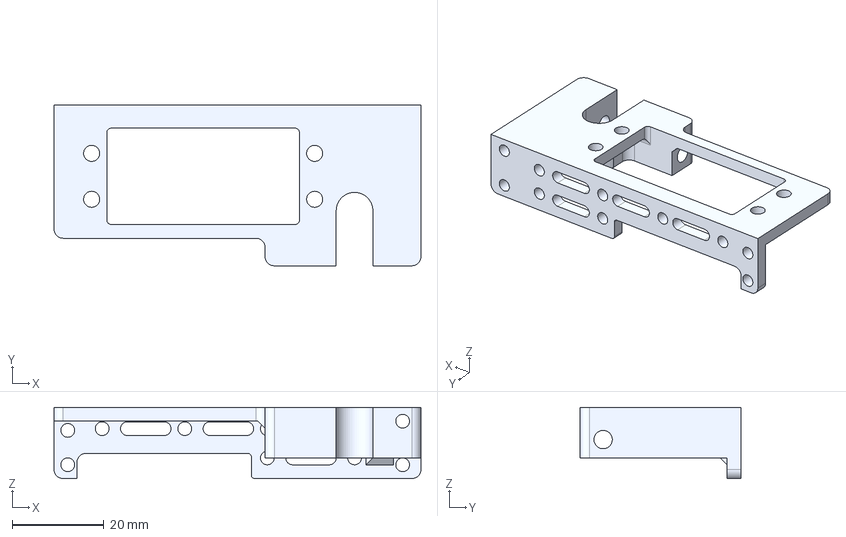
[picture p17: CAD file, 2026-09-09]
payloads/Payload-latch/CAD/V1-Servo-Payload-Mount.step
80.0 x 35.0 x 15.5 mm

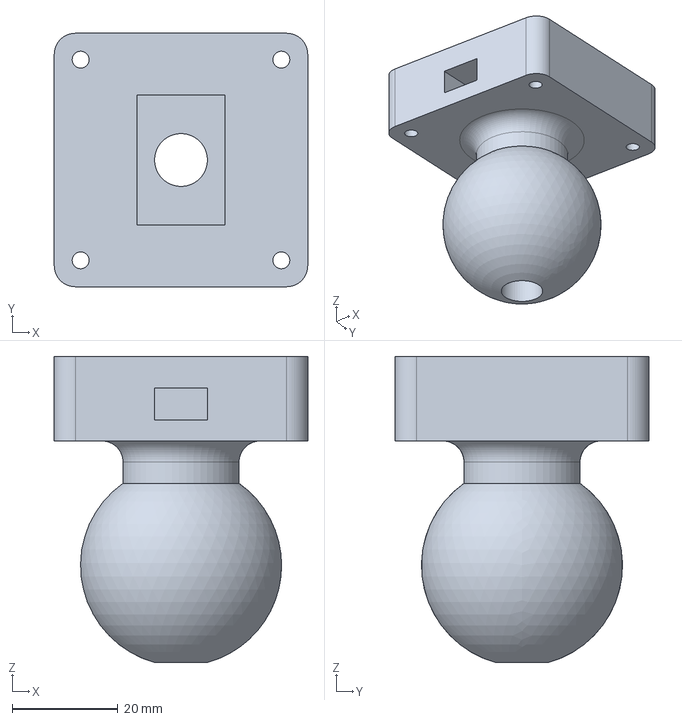
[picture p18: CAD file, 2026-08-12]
payloads/ram-ball-c/cad/ram_ball_c_adapter.step
48.0 x 48.0 x 57.9 mm

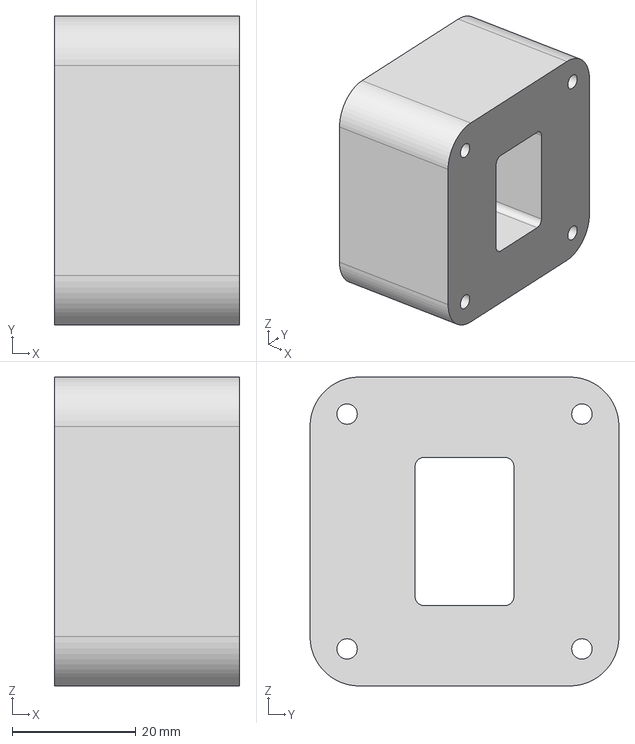
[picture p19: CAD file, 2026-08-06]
interface/mechanical/2111_attach_spacer.step
30.0 x 50.0 x 50.0 mm

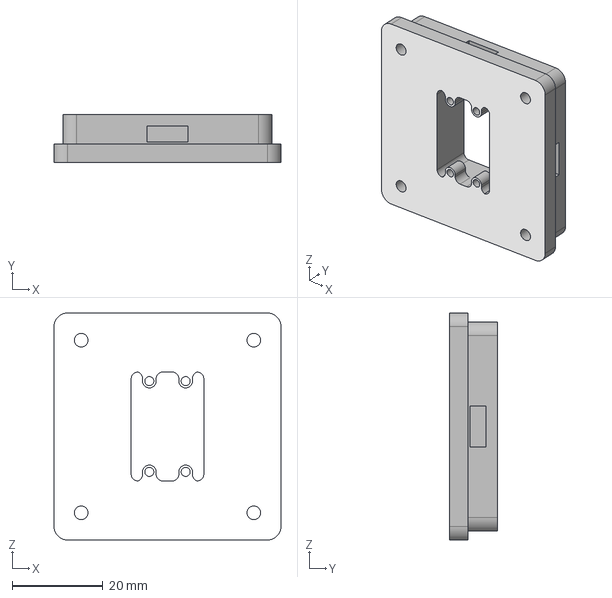
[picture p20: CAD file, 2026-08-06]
interface/mechanical/2112_attach_plate_payload_side.step
50.0 x 10.5 x 50.0 mm

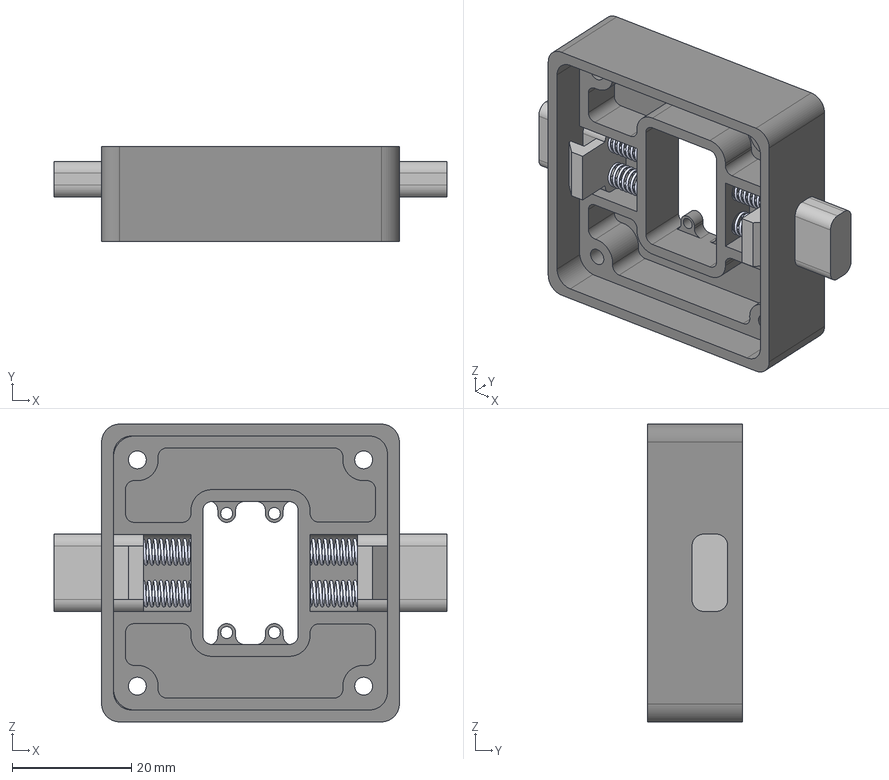
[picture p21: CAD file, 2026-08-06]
interface/mechanical/2112_attach_plate.step
66.0 x 16.0 x 50.0 mm
Fixed Top V4.0
Press PIN x 2
spring QRM x 4

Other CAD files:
payloads/Multispectral-Camera/CAD/MAPIR-Survey3N-RGN-adapter.stl
payloads/Payload-latch/CAD/V1-Servo-Payload-Mount.stl
payloads/ram-ball-c/cad/ram_ball_c_adapter.stl

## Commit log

2026-03-13 init: payload systems repo with README and attachment interface docs
2026-08-06 interface: add versioned ICD, mechanical mate files, payload template
    - ICD v1.0-draft verified against current Main PCB KiCad netlist:
    per-port capability matrix (CAN2 all ports, Ethernet all ports,
    12VSW bottom-only 2A, 12V_PL SSR-gated via FMU_CH4, per-port PWM)
    - vendor quick-release STEP files + mounting coordinates from BOM 2100
    - payload template folder; README corrected (drop UART and always-on
    12V claims) and pointed at the ICD
    [2111_attach_spacer.step, 2112_attach_plate.step, 2131_attach_spacer_bottom.step]
2026-08-06 review feedback: drop historical note and Quiver Mini, add payload-side plate docs, replace proposed list with call to action
2026-08-06 mechanical: add payload-side clip plate STEP (Replaceable Base, from Fusion master)
    [2112_attach_plate_payload_side.step]
2026-08-11 ram-ball-c: printed RAM Size-C ball adapter for the attachment interface
    One-part payload: bolts to the payload-side clip plate (measured r6
    clip-plate map: M2 at +/-19,+/-19; 16x24 blind-mate shaft), exposes a
    1.5" Size-C ball on a tangent neck, and passes wiring out either a
    10x6 side channel or a D10 axial bore exiting the ball pole clear of
    the RAM clamp band. Exports + 12-check independent verifier + renders.
    [ram_ball_c_adapter.step, ram_ball_c_adapter.stl]
2026-08-12 ram-ball-c: mounting holes now Ø3.2 through-holes (requested by Thomas)
    Blind 5.2 mm insert bores -> through the full 16 mm body. Same Ø works
    for M2 heat-set inserts pressed into the top, or through-bolting if the
    clip half's D3.9 head pockets allow. Verifier updated: through check at
    -2/-8/-15.5 at all four positions; 12/12 pass.
    [ram_ball_c_adapter.step, ram_ball_c_adapter.stl]
2026-08-12 ram-ball-c: README feedback from Thomas
    Drop champion/discussion lines and the M2 mounting detail (not relevant
    to this part), rename blind-mate PCB -> attachment interface PCB, note
    first article printed in PA6-CF, status design -> prototype.
2026-09-09 Uploading Attachment CAD files and
    [MAPIR-Survey3N-RGN-adapter.step, MAPIR-Survey3N-RGN-adapter.stl, V1-Servo-Payload-Mount.step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]
